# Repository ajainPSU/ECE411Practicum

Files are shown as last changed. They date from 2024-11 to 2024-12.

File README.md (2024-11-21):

# ECE411Practicum

## Team 12 Members:
- Felix Moss
- Davyd Gamza
- Alex Jain
- Anthony Le

### Project: Fingerprint + RFID Lockbox

This repository contains code and resources for the **Fingerprint + RFID Lockbox** project developed as part of the ECE 411 practicum. The project utilizes an **ESP32 Wroom** microcontroller to integrate fingerprint and RFID authentication for a secure lockbox system. The system is capable of reading RFID tags and verifying fingerprints to grant or deny access, with an optional relay mechanism to unlock the box.

---

### Key Features:

- **Fingerprint Authentication:** Using an **Adafruit Fingerprint Sensor** to match user fingerprints.
- **RFID Authentication:** Using the **MFRC522 RFID module** to scan RFID tags and validate the user.
- **TFT Display:** Displays system status and instructions on a **TFT ILI9163C display**.
- **Relay Control:** Unlocks the lockbox for a set duration upon successful authentication.
- **ESP32 Wroom:** The system is built on the **ESP32 Wroom** module, allowing for robust processing and connectivity.

---

### Repository Overview:

- **Bill_of_Materials:** List of components used in the project.
- **Display_Module:** Code for testing the TFT display with the ESP32 Wroom.
- **ESP32_Feather_Wifi_Database (No Longer Needed):** Previously used for WiFi connectivity and database management.
- **ESP32_Practicum:** Updated version of the main project file.
- **Fingerprint Sensor Module:** Code for testing and using the fingerprint sensor.
- **Fully Integrated Module:** Complete system code integrating RFID, fingerprint sensor, and relay.
- **Functional_Decomp:** Decomposition of the system into functional parts for easier development and testing.
- **LockTest:** Testing the lock mechanism functionality.
- **RFID Module:** Code for working with the MFRC522 RFID module.
- **Team_Meeting_Notes:** Notes from team meetings and discussions.
- **Temporary Files:** Placeholder for temporary or discarded files.
- **WroomTest:** Code for testing ESP32 Wroom functionality with serial print statements.

---

### Notes:
- The **ESP32_Feather_Wifi_Database** folder is no longer necessary and has been removed from the active project files.
- Make sure to check the **Fingerprint Sensor Module** and **Fully Integrated Module** for the latest updates on the system functionality.

---

### License:
This project is licensed under the [GPL-3.0 license](LICENSE).

---

### Setup Instructions:

1. **Hardware:**
   - **ESP32 Wroom** module
   - **Adafruit Fingerprint Sensor** (UART-based)
   - **MFRC522 RFID module**
   - **TFT ILI9163C display**
   - **Relay for lock mechanism**

2. **Software:**
   - Install the necessary libraries:
     - **Adafruit Fingerprint Sensor Library**
     - **Adafruit GFX Library**
     - **MFRC522 RFID Library**
     - **TFT ILI9163C Library**

3. **Connections:**
   - Refer to the individual files for pin connections and hardware setup.

---

### Getting Started:
1. Clone the repository to your local machine:
   ```bash
   git clone https://github.com/ajainPSU/ECE411Practicum.git

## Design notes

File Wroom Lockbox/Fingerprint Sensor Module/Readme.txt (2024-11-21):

Note* The enrollment is bugged for esp32_Wroom_fingertest
- Use Enroll_Only to enroll fingerprint on scanner

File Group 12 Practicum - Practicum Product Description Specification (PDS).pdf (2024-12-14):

# Fingerprint Sensor Lock

### Team 12

November 1, 2024

Anthony Le
Alex Jain
Davyd Gamza
Felix Moss

What does it do?

- The user first registers their fingerprint on the device. To access the box, they place their finger on the fingerprint sensor, which sends the input to the processor (Arduino/ESP32). If authorized, the system unlocks the door and displays the message “Authorized”. If unauthorized, a message will appear saying, "You are not authorized."
- The product can be used in many different contexts. Homeowners can secure items without keys, preventing unauthorized access. Businesses can use it for office doors, server rooms, or restricted areas, ensuring only authorized staff can enter. Factories and warehouses can secure equipment rooms or sensitive areas, reducing theft and unauthorized entry. Universities, hospitals, and labs can limit access to sensitive information or materials.

Market Analysis
- People who want to not carry around keys all the time can use this to unlock or enable doors, garages, hatches, etc.
- Competition includes other similar devices such as “Ring” which are electronic types of keys to unlock items. We differ from Ring as we have physical feedback for unauthorized entry attempts.
- Potential selling point is $25. Price is cheap enough to be widely available to everyday users and materials would be around cost once in mass production. The custom pcb, materials, and labor are the driving factors of why it’s priced the way it is.
- Optionally if the customer prefers not to change batteries they can purchase a wall adapter kit for an additional cost, but it will be a battery design from the box.
- Our primary consumers are home and business owners who wish to physically protect their buildings.

Requirements
- Must
- Be plugged into the wall for power.
- Take in fingerprints as input.
- Accurately read fingerprints and verify if the user is authorized.
- Display a message upon reading fingerprint
- Open lock for the user upon activation.
- Store fingerprint information.
- Relock itself after5 Seconds..
- Have an RFID scanner for 2-factor authentication
- May
- Have an optional battery for power to function without the wall plug
- Generate a log whenever the box is accessed or denies entry as a .txt file
- Have a sleek and visually appealing design.
- Re-lock the box and return to waiting for fingerprint input after being closed
- Have cutouts in the housing for the screen and rfid
- Have mounting points or brackets for stability purposes
- Should
- Include user instructions emphasizing proper use and handling to avoid tampering.
- Have user interface options for lock box settings on the display
- Have customizable status updates and alerts for the box owner
- Have a manual lock in case of technical failure
- Stand up to repeated attempts of unauthorized forced entry.

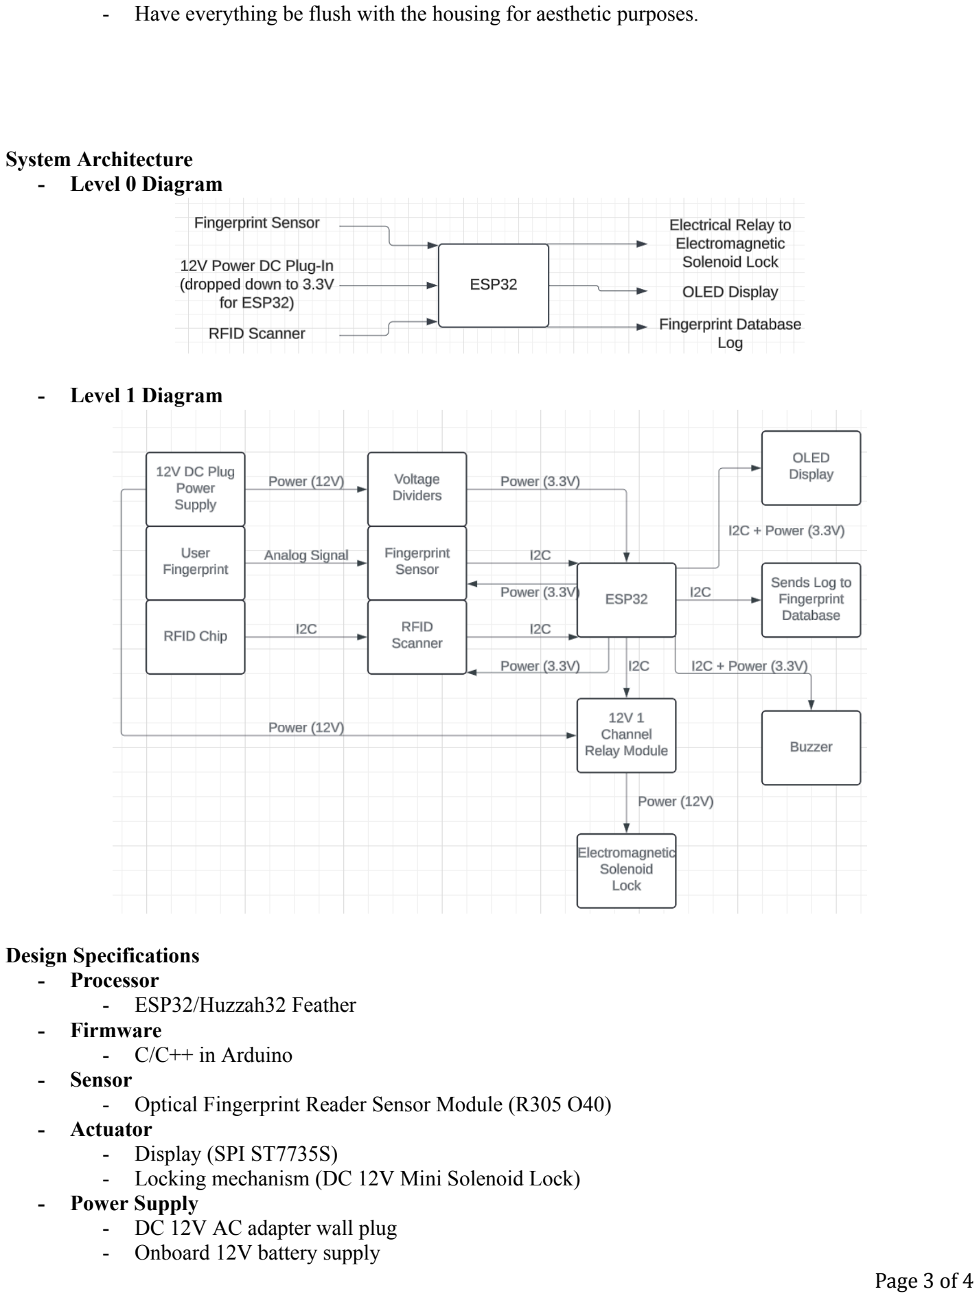
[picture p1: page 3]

- Have everything be flush with the housing for aesthetic purposes.

System Architecture
- Level 0 Diagram
- Level 1 Diagram

Design Specifications
- Processor
- ESP32/Huzzah32 Feather
- Firmware
- C/C++ in Arduino
- Sensor
- Optical Fingerprint Reader Sensor Module (R305 O40)
- Actuator
- Display (SPI ST7735S)
- Locking mechanism (DC 12V Mini Solenoid Lock)
- Power Supply
- DC 12V AC adapter wall plug
- Onboard 12V battery supply

- Secondary battery supply (Higher Voltage)

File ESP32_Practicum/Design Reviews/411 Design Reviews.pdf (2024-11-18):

# Design Review 1

## Conducted by Team 8 (Eric Sanman and Chuong Vo)

# Schematic

- Pull-up resistors for I2C connections
- Move power input to left side of schematic
- Add 0.1uF from 12v input to gnd
- Add box around regulator and other circuit areas for explanation
- Add resistors to high current pin connections

# PCB

- Keep traces away from edges of board, DRC compliant
- Use ground planes better
- 2.54mm between pins
- Use 0805 size resistors, label them on pcb
- Make pcb larger
- Make power traces larger

# Overall

- Add broken component warning

# Design Review 2

## Conducted by Andrew Greenberg (In-Class)

# Schematic

- Use 5V symbol for VCC (instead of lines)
- Add connector symbol to 12V input
- Label connections instead of lines “UR OUT” “UR TX”
- Power to esp ->critical to function-> add capacitors to ground
- Add bypass capacitors to multiple locations as needed
- I^2C missing 4.7k Ohm resistors-> add in physical pull up resistors, don't use software
- 3.3V add symbol and label for where power comes from, don’t use lines
- SDA TO SDK add test points
- Add test points as needed
- Add snubber diode-> reverse bias parallel with the coil
- Add led’s for heartbeat monitoring and for testing
- Use ground symbol instead of wires
- Add test points
- C1 & C2 check floating pins, no pins should be floating-> if floating make it go to a test point->

# PCB

- Add test points
- Use test point diameter .1” or 1mm holes
- Add stitching-> ground to vias
- Use thick wires 10, 20, 30 mm

# Overall

- Version and date are good
- Add to the schematic first then to the PCB
- Relay-> will relay click at 3.3V? (GPIO 32), if not use smaller relay that will click sooner or use the 5 volt rail and try click it

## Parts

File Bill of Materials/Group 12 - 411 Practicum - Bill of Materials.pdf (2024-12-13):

Bill Of Materials for: Group 12
Last modified: 12/12/2024
PCB version: 2.3
BOM revision: 2.3.3 | P/NP = Place/Not Place
Cnt | Part References | P/NP | Mfg | Mfg PN | Description | Dist | Dist Part Number | Cost Ea. | Cost Total
1 | C0 | P | ESPRESSIF | N/A | ESP32 Microcontroller | Amazon | B08D5ZD528 | 5.33 | 5.33
1 | C1 | NP | Handson Tech | N/A | RF RC522 Reader IC Card Sensor Module | Amazon | B07KGBJ9VG | 3.99 | 3.99
1 | C2 | NP | RAJGURU | N/A | Fingerprint Scanner | Amazon | B089LXDG94 | 19.33 | 19.33
1 | C3 | NP | ILITEK | N/A | OLED Display | Amazon | 3-01-1435 | 8.49 | 8.49
1 | C4 | NP | STMicroelectronics | N/A | Voltage Regulator | Mouser | 511-LM317T | 0.63 | 0.63
1 | C5 | NP | HiLetgo | N/A | 5V One Channel Relay Module | Amazon | B00LW15A4W | 3.7 | 3.70
1 | C6 | NP | ATOPLEE | 15060012S02 | Solenoid Lock | Amazon | 759218167424 | 3.99 | 3.99
1 | C7C | NP | California JOS | N/A | 12V DC Power Jack | Amazon | B09ZBN38FS | 1.39 | 6.99
1 | N/A | NP | LitStar | N/A | 12V 2A AC Adapter Charger | Amazon | B0852HX9HV | 11.99 | 11.99
2 | C15, C13 | P | KYOCERA AVX | 08055C104J4T2A | 0.1uF Capacitor | Digikey | 478-KAM21BR71H104JTTR-ND | 0.107 | 0.21
1 | C14 | P | Diodes Inc. | 1N418W-7-F | Rectifier Diode | Digikey | 1N4148W-FDITR-ND | 0.091 | 0.09
2 | C11, C12 | P | onsemi | 1N4007G | Flyback Diode | Digikey | 1N4007GOS-ND | 0.131 | 0.26
1 | C8 | P | Murata Electronics | GRM21BR60G107ME11L | 100uF Capacitor | Digikey | 490-13980-2-ND | 0.458 | 0.46
2 | R4, R5 | P | Panasonic Elec. Comp. | ERJ-6ENF4701V | 4.7k Resistor | Digikey | P4.70KCTR-ND | 0.052 | 0.10
1 | R3 | P | YAGEO | RC0805FR-071KL | 1k Resistor | Digikey | 311-1.00KCRTR-ND | 0.016 | 0.16
1 | R1 | P | Panasonic Elec. Comp. | ERA6AEB241V | 240 Resistor | Digikey | 10-ERA-6AEB241VTR-ND | 0.101 | 1.01
1 | R2 | P | YAGEO | RT0805BRD07723RL | 723 REsistor | Digikey | 13-RT0805BRD07723RLCT-ND | 0.126 | 1.26
1 | C9 | P | KEMET | C0805C106K8PACTU | 10uF Cap | Digikey | 399-C0805C106K8PAC7800CT-ND | 0.073 | 0.07
2 | N/A | NP | PSU Electronic Prototyping Lab | N/A | 3D Printed Box | PSU | N/A | 4.65 | 9.30
1 | N/A | P | OSHPARK | N/A | PCB | OSHPARK | N/A | 9.03 | 9.03
| | | | | | | | TOTAL: | 86.40
VERSION INFO
Rev | Date | Notes
1 | 2024-11-14 Initial BOM
1.2 | 2024-11-18 Updates from Design Reviews
2.3 | 2024-11-20 Verison 2.3 Updates
2.3.1 | 2024-12-4 Formatting and Information Updates
2.3.2 | 2024-12-9 Information Updates
2.3.3 | 2024-12-24 Information Updates

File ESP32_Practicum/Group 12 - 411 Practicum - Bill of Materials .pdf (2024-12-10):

Bill Of Materials for: Group 12
Last modified: 12/9/2024
PCB version: 2.3
BOM revision: 2.3.2 | P/NP = Place/Not Place
Cnt | Part References | P/NP | Mfg | Mfg PN | Description | Dist | Dist Part Number | Cost Ea. | Cost Total
1 | C0 | P | ESPRESSIF | N/A | ESP32 Microcontroller | Amazon | B08D5ZD528 | 5.33 | 15.99
1 | C1 | NP | Handson Tech | N/A | RF RC522 Reader IC Card Sensor Module | Amazon | B07KGBJ9VG | 3.99 | 15.99
1 | C2 | NP | RAJGURU | N/A | Fingerprint Scanner | Amazon | B089LXDG94 | 19.33 | 19.33
1 | C3 | NP | ILITEK | N/A | OLED Display | Amazon | 3-01-1435 | 8.49 | 8.49
1 | C4 | NP | STMicroelectronics | N/A | Voltage Regulator | Mouser | 511-LM317T | 0.63 | 0.63
1 | C5 | NP | HiLetgo | N/A | 2pcs 5V One Channel Relay Module | Amazon | B00LW15A4W | 3.7 | 7.39
1 | C6 | NP | ATOPLEE | 15060012S02 | Solenoid Lock | Amazon | 759218167424 | 3.99 | 15.99
1 | C7C | NP | California JOS | N/A | 12V DC Power Jack | Amazon | B09ZBN38FS | 1.39 | 6.99
1 | N/A | NP | LitStar | N/A | 12V 2A AC Adapter Charger | Amazon | B0852HX9HV | 11.99 | 11.99
2 | C15, C13 | P | KYOCERA AVX | 08055C104J4T2A | 0.1uF Capacitor | Digikey | 478-KAM21BR71H104JTTR-ND | 0.107 | 1.07
1 | C14 | P | Diodes Inc. | 1N418W-7-F | Rectifier Diode | Digikey | 1N4148W-FDITR-ND | 0.091 | 0.91
2 | C11, C12 | P | onsemi | 1N4007G | Flyback Diode | Digikey | 1N4007GOS-ND | 0.131 | 1.31
1 | C8 | P | Murata Electronics | GRM21BR60G107ME11L | 100uF Capacitor | Digikey | 490-13980-2-ND | 0.458 | 4.58
2 | R4, R5 | P | Panasonic Elec. Comp. | ERJ-6ENF4701V | 4.7k Resistor | Digikey | P4.70KCTR-ND | 0.052 | 0.52
1 | R3 | P | YAGEO | RC0805FR-071KL | 1k Resistor | Digikey | 311-1.00KCRTR-ND | 0.016 | 0.16
1 | R1 | P | Panasonic Elec. Comp. | ERA6AEB241V | 240 Resistor | Digikey | 10-ERA-6AEB241VTR-ND | 0.101 | 1.01
1 | R2 | P | YAGEO | RT0805BRD07723RL | 723 REsistor | Digikey | 13-RT0805BRD07723RLCT-ND | 0.126 | 1.26
1 | C9 | P | KEMET | C0805C106K8PACTU | 10uF Cap | Digikey | 399-C0805C106K8PAC7800CT-ND | 0.073 | 0.73
1 | N/A | NP | PSU Electronic Prototyping Lab | N/A | 3D Printed Box | PSU | N/A | 4.65 | 4.65
| | | | | | | | TOTAL: | 118.99
VERSION INFO
Rev | Date | Notes
1 | 2024-11-14 Initial BOM
1.2 | 2024-11-18 Updates from Design Reviews
2.3 | 2024-11-20 Verison 2.3 Updates
2.3.1 | 2024-12-4 Formatting and Information Updates
2.3.2 | 2024-12-9 Information Updates

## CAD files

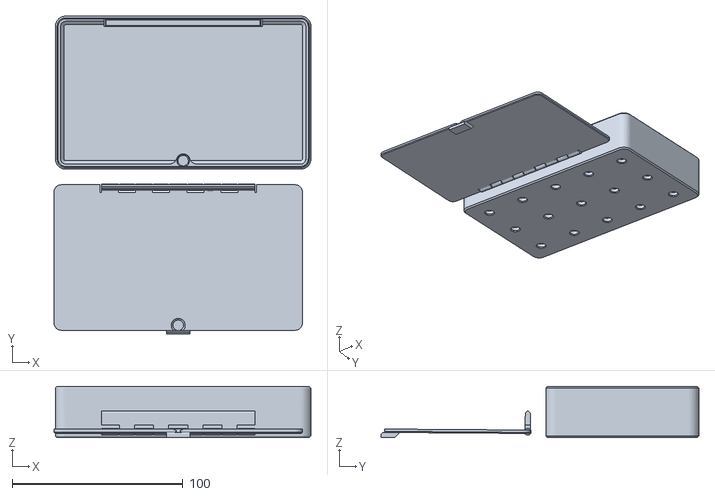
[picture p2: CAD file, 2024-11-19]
Alternatives/Other.stl
150.4 x 186.0 x 30.0

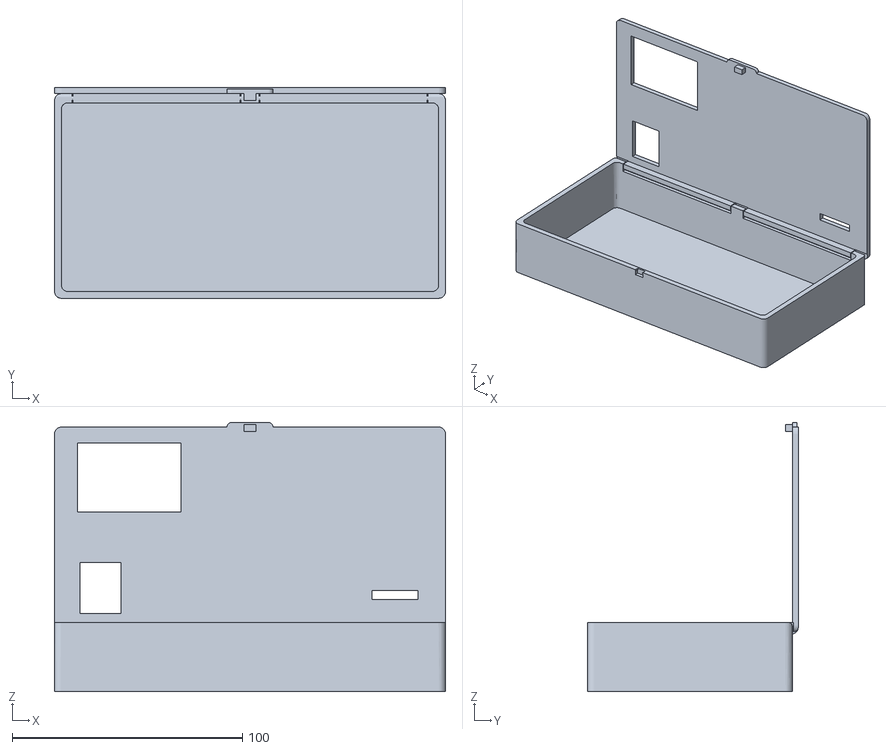
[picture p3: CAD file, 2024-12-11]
Box v3.0/v3.1.stl
170.0 x 91.6 x 117.0

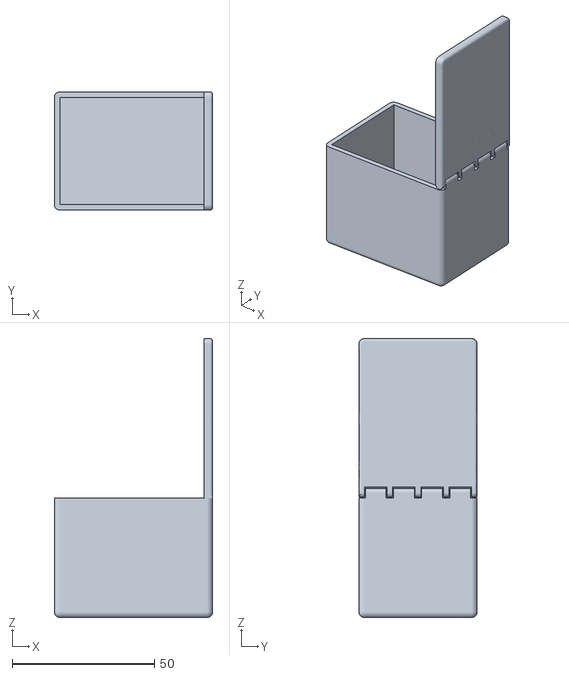
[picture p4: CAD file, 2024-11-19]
Alternatives/Print In Place.stl
55.7 x 41.6 x 98.0

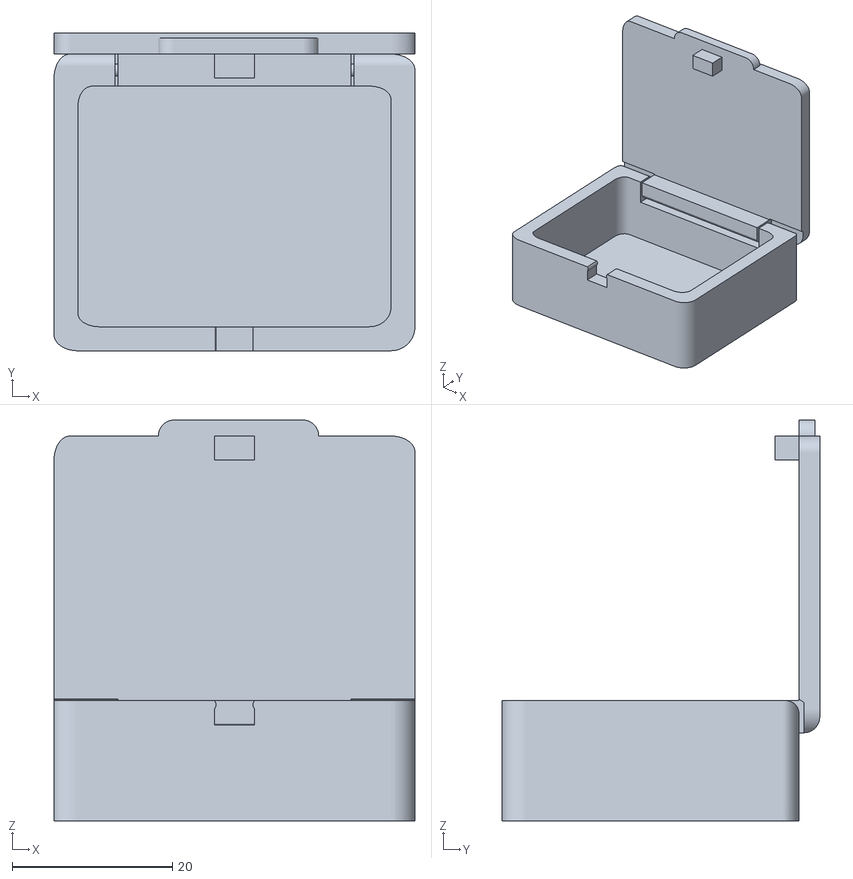
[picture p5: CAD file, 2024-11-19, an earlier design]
Box v.1/v1.1.stl
45.0 x 39.6 x 50.0

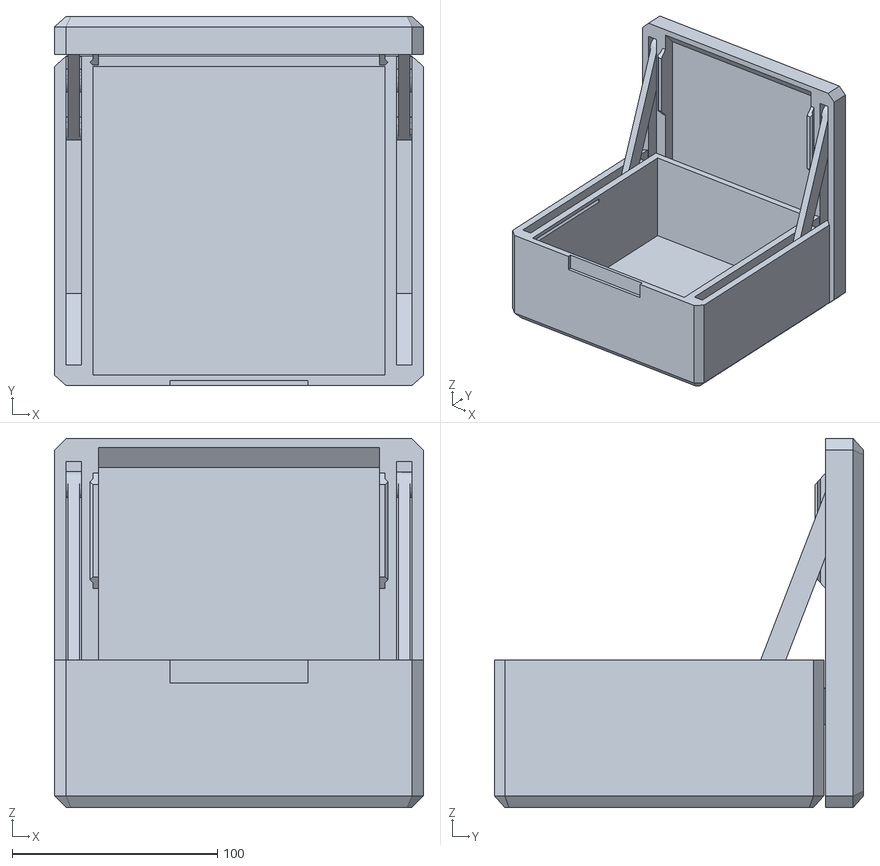
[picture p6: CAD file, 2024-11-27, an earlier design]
Box v2.0/v2.3.stl
180.0 x 180.0 x 180.0

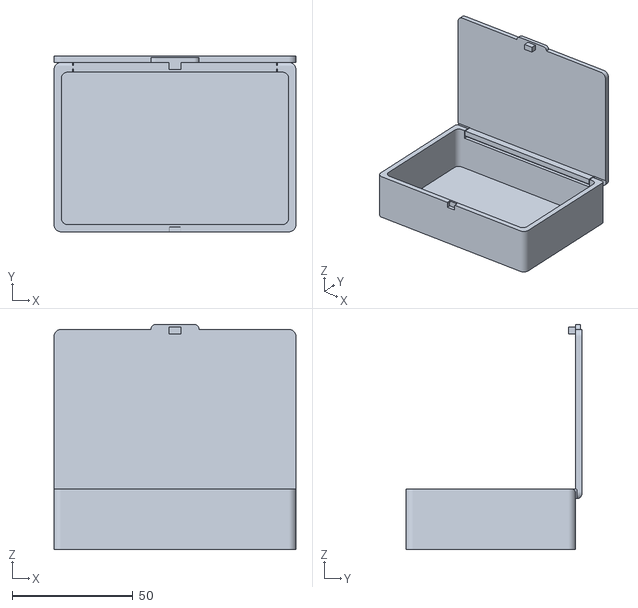
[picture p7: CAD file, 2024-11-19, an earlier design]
Box v.1/v1.2.stl
100.0 x 72.6 x 93.0

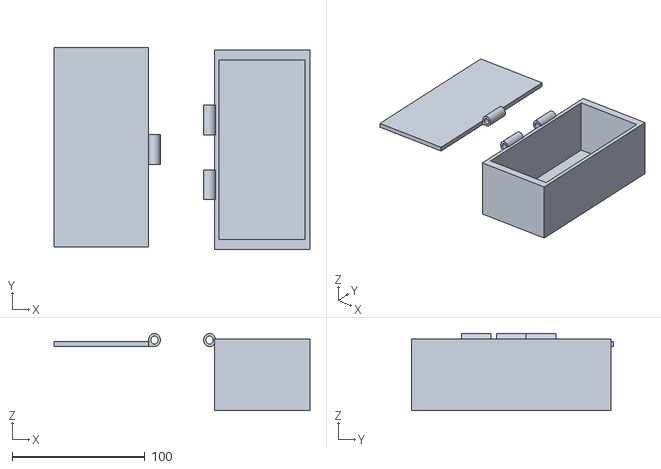
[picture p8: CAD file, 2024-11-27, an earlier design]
Box v2.0/v2.2.stl
192.5 x 152.0 x 58.0

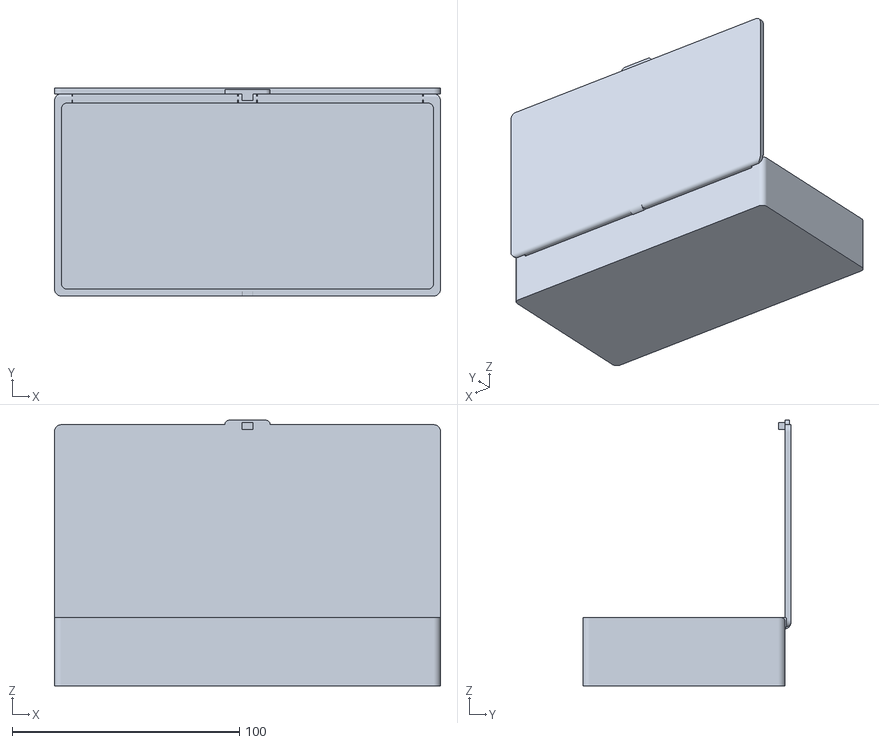
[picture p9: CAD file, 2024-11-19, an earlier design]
Box v.1/v1.3.stl
170.0 x 91.6 x 117.0

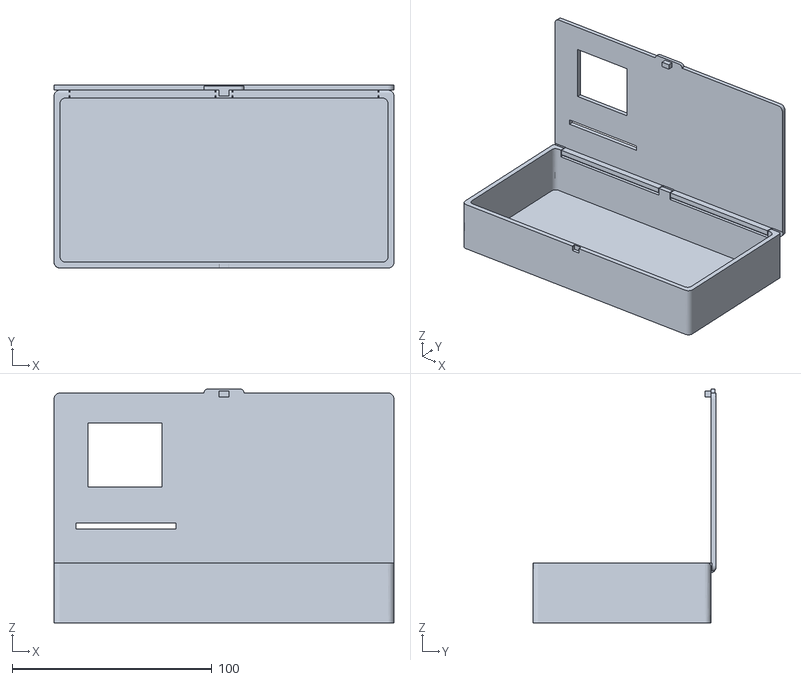
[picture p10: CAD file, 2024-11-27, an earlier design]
Box v2.0/v2.1.stl
170.0 x 91.6 x 117.0

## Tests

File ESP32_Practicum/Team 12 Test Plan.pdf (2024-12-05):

# Team 12 Fingerprint Sensor Lock Box Testing

## List

Unit Tests

### 1. Power Supply Testing

- Verify LM317T regulator provides a stable 3.3V output for ESP32.
- Verify relay module receives 3.3V for actuation.
- Confirm 5V output from the power supply matches specifications.

### 2. ESP32 Microcontroller

- Test ESP32 boot sequence displays proper messages on serial monitor.
- Verify all pins supply correct voltages as per design (e.g., 3.3V, 5V).
- Run the "Blink" program to confirm code upload functionality.

### 3. R307 Fingerprint Sensor

- Test successful enrollment of a fingerprint.
- Verify matching functionality for enrolled fingerprints.
- Test error handling for non-enrolled fingerprints and faulty connections.

### 4. RC522 RFID Module

- Verify pin connections with a multimeter (e.g., continuity testing).
- Test module functionality: scan valid and invalid RFID tags.

### 5. TFT LCD Display

- Verify successful power-on (blank screen).
- Test display functionality for dynamic text changes and color cycling.

### 6. Relay Module and Solenoid Lock

- Verify relay receives appropriate signals from ESP32.
- Confirm solenoid lock actuates correctly when powered.
2024-12-4 | Page 1 of 18

Verification Tests

1. The system boots and displays the correct startup sequence on the LCD.
2. The fingerprint sensor successfully enrolls fingerprints and stores them in the database.
3. The system matches a scanned fingerprint against the database and grants/denies access appropriately.
4. The RFID module correctly identifies valid and invalid tags.
5. Solenoid lock unlocks when the correct fingerprint and RFID tag are scanned.
6. Solenoid lock relocks after a set timeout duration.
7. The LCD updates dynamically during operations (e.g., shows “Access Granted” or “Denied”).
8. Error messages display for failed sensor connections or invalid inputs.
9. Entire system functions under varying input voltages (e.g., 8V, 12V).
10. Database operations work: add, retrieve, delete, and clear fingerprints.
11. Relay and solenoid lock function without signal delays or mismatches.
12. Overall system integration handles sequential operations without malfunction (e.g., RFID → Fingerprint → Unlock).
2024-12-4 | Page 2 of 18

Validation Tests

### 1. Requirement: Access Control

- Test that only a valid RFID and fingerprint combination grants access.

### 2. Requirement: Power Reliability

- Validate the system operates consistently at 12V power supply input.

### 3. Requirement: Error Handling

- Test that an error is displayed when a non-enrolled fingerprint is scanned.
- Simulate a disconnected fingerprint sensor and confirm error detection.

### 4. Requirement: User Feedback

- Validate that all user actions (e.g., scanning RFID, placing a fingerprint) are acknowledged with correct LCD output.

### 5. Requirement: Lock Functionality

- Confirm solenoid lock unlocks for 5 seconds and relocks automatically.

### 6. Requirement: Security

- Test that unregistered RFID tags and fingerprints cannot gain access.

### 7. Requirement: Database Management

- Validate addition, retrieval, and deletion of fingerprint records work as specified.

### 8. Requirement: Display Functionality

- Ensure the TFT LCD correctly displays all critical statuses and instructions.
2024-12-4 | Page 3 of 18

# Matrix Test

Test Author: Felix Moss, Anthony Le

Test Case Name: | Varying Input Voltage Test #1 | Test ID #: | 012
Description: | We will be inputting several different voltages to our circuit and determining if it functions properly. | Type: | ✅white box □ black box □ _____________

Tester Information

| Name of Tester: | Felix Moss | Date: | 12/3/24
| HW/SW Version: | V2.3 | Time: | 4:25 PM
| Setup: | Attach Lab 12V DC Power Supply to PCB for testing.
T E S T | INPUTS | EXPECTED OUTPUTS | P A S S | F A I L | N / A | Comments
1 | 3V3 Input Voltage | Circuit should perform as expected | | ❌ | | No circuit response
2 | 5V Input Voltage | Circuit should perform as expected | | ❌ | | ESP32 barely on, relay on, everything else off
3 | 8V Input Voltage | Circuit should perform as expected | | ❌ | | All circuit elements work except for the solenoid lock.
2024-12-4 | Page 4 of 18

4 | 10V Input Voltage | Circuit should perform as expected | | ❌ | All circuit elements work except for the solenoid lock.
5 | 12V Input Voltage | Circuit should perform as expected | ✅ | | Circuit performs as normal
| Overall test result: | | ✅ | | Circuit performed as expected
2024-12-4 | Page 5 of 18

# Test Cases

Test Author: Anthony Le

Test Case Name: | ESP32 WROOM Blink Test and pin testing #1 | Test ID #: | 001
Description: | Testing the Wroom LED to make sure it can actually upload code and that all the pins that are used are properly working | Type: | ✅ white box □ black box □ ________

Tester Information
| Name of Tester: | Anthony and Felix | Date: | 12/1/2024
| HW/SW Version: | V2.3 | Time: | 5:31 PM
| Setup: | Soldered Wroom to PCB and should blink and have all power pins supplying correct voltages
S T E P | Action | Expected Result | P A S S | F A I L | N / A | Comments
1 | Power on the Wroom | A Red LED should light up on the board meaning there is power | ✅
2 | Blinking LED | A program should run that will blink an led and display message via serial port | ✅
3 | Check power test points | Make sure all the power pins are working properly | | ❌ | | 3.3V was showing 0.7 V but we realized we soldered the Wroom backwards
| Overall test result: | | | ❌ | | Need to fix the Wroom orientation and fix it again
2024-12-4 | Page 6 of 18

Test Author: Anthony Le

Test Case Name: | ESP32 WROOM Blink Test and pin testing #2 | Test ID #: | 002
Description: | Testing the Wroom LED to make sure it can actually upload code and that all the pins that are used are properly working | Type: | ✅ white box □ black box □ ________

Tester Information
| Name of Tester: | Anthony and Felix | Date: | 12/1/2024
| HW/SW Version: | V2.3 | Time: | 5:31 PM
| Setup: | Soldered Wroom to PCB and should blink and have all power pins supplying correct voltages
S T E P | Action | Expected Result | P A S S | F A I L | N / A | Comments
1 | Power on the Wroom | | ✅
2 | Blinking LED | | ✅
3 | Check power test points | | ✅
| Overall test result: | | ✅ | | | After desoldering and resoldering the Wroom, it performed as expected
2024-12-4 | Page 7 of 18

Test Author: Anthony Le
Test Case Name: | Software Fingerprint Sensor R307 Functionalities Test #1 | Test ID #: | 003
Description: | This test case evaluates the performance and functionalities of the R307 Fingerprint Sensor, including fingerprint enrollment, verification, database management, and error handling. The goal is to ensure that the sensor operates reliably and meets specified requirements under various conditions. | Type: | ✅ white box □ black box □ ________

Tester Information
| Name of Tester: | Anthony Le | Date: | 12/01/2024
| HW/SW Version: | V2.3 | Time: | 7:30 PM
| Setup: | Hardware and software setup required for testing R307 Fingerprint Sensor and the connected AS609 chip.
S T E P | Action | Expected Result | P A S S | F A I L | N / A | Comments
1 | Enroll a fingerprint onto the AS609 chip | Place a finger on the sensor, and the system should successfully scan and store the fingerprint. A message confirming the enrollment should be displayed, and the fingerprint data should be added to the database. | ✅ | | | ESP initially did not recognize fingerprints. It was identified as a pin connection issue and was quickly rectified.
2 | Verify fingerprint | Place the same finger on the sensor. The system should recognize the fingerprint, match it to the stored data, and display a success message. | ✅
3 | Display selected fingerprint information | Request details about a specific fingerprint using its ID. The system should retrieve and display relevant information, such as fingerprint ID or storage index. | ✅
4 | Display all fingerprints stored on chip | Request a list of all stored fingerprints. The system should output all fingerprint IDs or indexes currently saved in the database. | ✅
5 | Delete a selected fingerprint | Specify a fingerprint ID to delete. The system should remove the fingerprint from the database and confirm the deletion with a message. | ✅
6 | Clear the fingerprint database | Issue a command to clear the database. The system should | ✅
2024-12-4 | Page 8 of 18

| | delete all fingerprints stored on the chip and display a confirmation message.
7 | Attempt to verify a non-enrolled fingerprint | Place an unregistered finger on the sensor. The system should fail to find a match, display an error message, and deny access. | ✅
8 | Simulate a failed sensor connection | Disconnect the sensor or interrupt communication. The system should detect the issue and display an error indicating a failed connection or unavailability. | ✅
| Overall test result: | | ✅ | Fingerprint scanner performed as expected.
2024-12-4 | Page 9 of 18

Test Author: Anthony Le
Test Case Name: | ESP32 Power Testing #3 | Test ID #: | 004
Description: | Testing all power connections from ESP32 to external modules | Type: | ✅ white box □ black box □ ________

Tester Information
| Name of Tester: | Felix Moss, Anthony Le | Date: | 12/1/24
| HW/SW Version: | V2.3 | Time: | 6:55 PM
| Setup: | Multimeter with alligator clips used on different pins and test points
S T E P | Action | Expected Result | P A S S | F A I L | N / A | Comments
1 | 3V3 Test Point | Should display ~3.3V | ✅
2 | 5V Test Point | Should display ~5V | ✅
3 | R307 VIN + GND | Should display ~3.3V | ✅
4 | RC522 RFID 3V3 + GND | Should display ~3.3V | ✅
5 | Relay Module DC+ + GND | Should display ~3.3V | ✅
6 | ST7735 OLED VCC + GND | Should display ~3.3V | ✅
| Overall test result: | | ✅ | | | All power connections matched expectations
2024-12-4 | Page 10 of 18

Test Author: Felix Moss, Anthony Le
Test Case Name: | Software TFT LCD Display #1 | Test ID #: | 005
Description: | Testing software on the TFT LCD Display | Type: | ✅ white box □ black box □ ________

Tester Information
| Name of Tester: | Felix Moss, Anthony Le | Date: | 12/1/24
| HW/SW Version: | 1.0 | Time: | 7:45 PM
| Setup: | Connect all pins of LCD to appropriate pins on PCB
S T E P | Action | Expected Result | P A S S | F A I L | N / A | Comments
1 | Turn on display | Should display blank screen | ✅
2 | Send signal from ESP32 | Should display “Hello World” text and cycle through colors | | ❌
| Overall test result: | | | ❌ | | LCD only turned on, nothing displayed on screen.
2024-12-4 | Page 11 of 18

Test Author: Felix Moss, Anthony Le
Test Case Name: | Software TFT LCD Display Test #2 | Test ID #: | 006
Description: | Testing software on the TFT LCD Display | Type: | ✅ white box □ black box □ ________

Tester Information
| Name of Tester: | Felix Moss, Anthony Le | Date: | 12/1/24
| HW/SW Version: | 1.2 | Time: | 7:45 PM
| Setup: | Connect all pins of LCD to appropriate pins on PCB
S T E P | Action | Expected Result | P A S S | F A I L | N / A | Comments
1 | Turn on display | Should display blank screen | ✅
2 | Send signal from ESP32 | Should display “Hello World” text and cycle through colors | ✅
| Overall test result: | | ✅ | | | Display performed as expected. Problem was determined to be a pin connection issue.
2024-12-4 | Page 12 of 18

Test Author: Felix Moss, Anthony Le
Test Case Name: | RC522 RFID Pin Connections and Software Testing #1 | Test ID #: | 007
Description: | Testing the pin connections and the software for the RC522 RFID scanner by verifying connections and running test code. | Type: | ✅ white box □ black box □ ________

Tester Information
| Name of Tester: | Felix Moss, Anthony | Date: | 12/1/24
| HW/SW Version: | V2.3 | Time: | 8:15 PM
| Setup: | Attach probes to Multimeter. Attach RC522 to appropriate pins.
S T E P | Action | Expected Result | P A S S | F A I L | N / A | Comments
1 | Test all RC522 pin connections | When touching the pin on the PCB to the corresponding pin on the ESP32, a beep should be heard | ✅
2 | Turn on RC522 | Should turn on red LED on scanner | ✅
3 | Upload software | Scans for RFID card and UID. Displays “Access Granted” on serial monitor if ID is correct. Displays “Access Denied” on serial monitor if ID is incorrect | ✅
| Overall test result: | | ✅ | | | RC522 performed as expected
2024-12-4 | Page 13 of 18

Test Author: Felix Moss, Anthony Le
Test Case Name: | Relay Module and Solenoid Lock Test #1 | Test ID #: | 008
Description: | Testing the pin connections and the software for the Relay Module and Solenoid Lock | Type: | ✅ white box □ black box □ ________

Tester Information
| Name of Tester: | Felix Moss, Anthony | Date: | 12/1/24
| HW/SW Version: | V2.3 | Time: | 8:45 PM
| Setup: | Attach probes to Multimeter. Attach Relay Module and Solenoid Lock to appropriate pins.
S T E P | Action | Expected Result | P A S S | F A I L | N / A | Comments
1 | Test all pin connections | When touching the pin on the PCB to the corresponding pin on the ESP32, a beep should be heard. | | ❌ | | Pin NO incorrectly routed. Fixed by connecting NO on the module directly to ground and leaving NO on the PCB unconnected.
2 | Turn on Relay Module | A red LED should light up on the Relay Module when the ESP32 is powered on | ✅
3 | Upload software | Solenoid lock should open and close | ✅
| Overall test result: | | ✅ | | | The relay performed as expected. However, since the NO pin on the PCB is wired incorrectly, the NO pin on the relay had to be directly wired to ground.
2024-12-4 | Page 14 of 18

Test Author: Felix Moss, Anthony Le
Test Case Name: | Full Integrated Test #1 | Test ID #: | 009
Description: | Testing the entire mechanism with all modules attached. | Type: | ✅ white box □ black box □ ________

Tester Information
| Name of Tester: | Felix Moss, Anthony | Date: | 12/1/24
| HW/SW Version: | V2.3 | Time: | 9:30 PM
| Setup: | Attach all modules to PCB. Run test software
S T E P | Action | Expected Result | P A S S | F A I L | N / A | Comments
1 | Run startup software | Display should show text saying, “Booting up System…”, “Fingerprint Sensor And RFID Scanner Initializing…”, “Access Control System”, and Finger Sensor Ready” | ✅
2 | Scan incorrect RFID | Display should show text saying, “Access Denied” and then return to “Scan RFID…” | ✅
3 | Scan correct RFID | Display should show text saying, “RFID Valid” and then show, “Place finger” | ✅
4 | Scan incorrect fingerprint | Display should show text saying, “Finger No Match” and then return to “Scan RFID” | ✅
5 | Scan correct RFID | Display should show text saying, “Access Granted” and then show, “Place finger” | ✅
6 | Scan correct fingerprint | Display should show text saying, “Access Granted, ID [User ID Number]” | ✅
7 | Solenoid Unlocks | Solenoid should unlock and display should say, “ Unlocked”. The lock should close after 5 seconds. | ✅
8 | Solenoid Locks | Solenoid should re-lock. The display should say, “ Locked”, | ✅
2024-12-4 | Page 15 of 18

| then return to “Scan RFID…”
Overall test result: | | ✅ | Mechanism performed as expected
2024-12-4 | Page 16 of 18

Test Author: Felix Moss

Test Case Name: | LM317T Testing #1 | Test ID #: | 010
Description: | Testing the LM317T voltage regulator to see if it can power the ESP32 with a 12V source. | Type: | ✅ white box □ black box □ ________

Tester Information
| Name of Tester: | Felix Moss | Date: | 12/3/2024
| HW/SW Version: | V2.3 | Time: | 12:30 PM
| Setup: | Solder LM317T to board. Set DC power supply to 12V and attach to board. Attach probes to Multimeter.
S T E P | Action | Expected Result | P A S S | F A I L | N / A | Comments
1 | Test LM317T pin connections | When touching the pin on the PCB to the corresponding pin on the ESP32, a beep should be heard. | ✅
2 | Turn on 12V power | A Red LED should light up on the ESP32 meaning there is power | | ❌ | | No light appeared and the power supply showed signs of a short.
| Overall test result: | | | ❌ | | Check all pin connections and rerun test
2024-12-4 | Page 17 of 18

Test Author: Felix Moss

Test Case Name: | LM317T Testing #2 | Test ID #: | 011
Description: | Testing the LM317T voltage regulator to see if it can power the ESP32 with a 12V source. | Type: | ✅ white box □ black box □ ________

Tester Information
| Name of Tester: | Felix Moss | Date: | 12/3/2024
| HW/SW Version: | V2.3 | Time: | 12:30 PM
| Setup: | Solder LM317T to board. Set DC power supply to 12V and attach to board. Attach probes to Multimeter.
S T E P | Action | Expected Result | P A S S | F A I L | N / A | Comments
1 | Test LM317T pin connections | When touching the pin on the PCB to the corresponding pin on the ESP32, a beep should be heard. | ✅
2 | Turn on 12V power | A Red LED should light up on the ESP32 meaning there is power | ✅
| Overall test result: | | ✅ | | | Problem was determined to be a short of some kind and was quickly rectified.
2024-12-4 | Page 18 of 18

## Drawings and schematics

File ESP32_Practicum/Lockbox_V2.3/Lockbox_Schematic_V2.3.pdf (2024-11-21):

D22 14 | D23 15 | D25 23 | D26 24 | D27 25 | D32 21 | D33 22 | D35 20 | D34 19

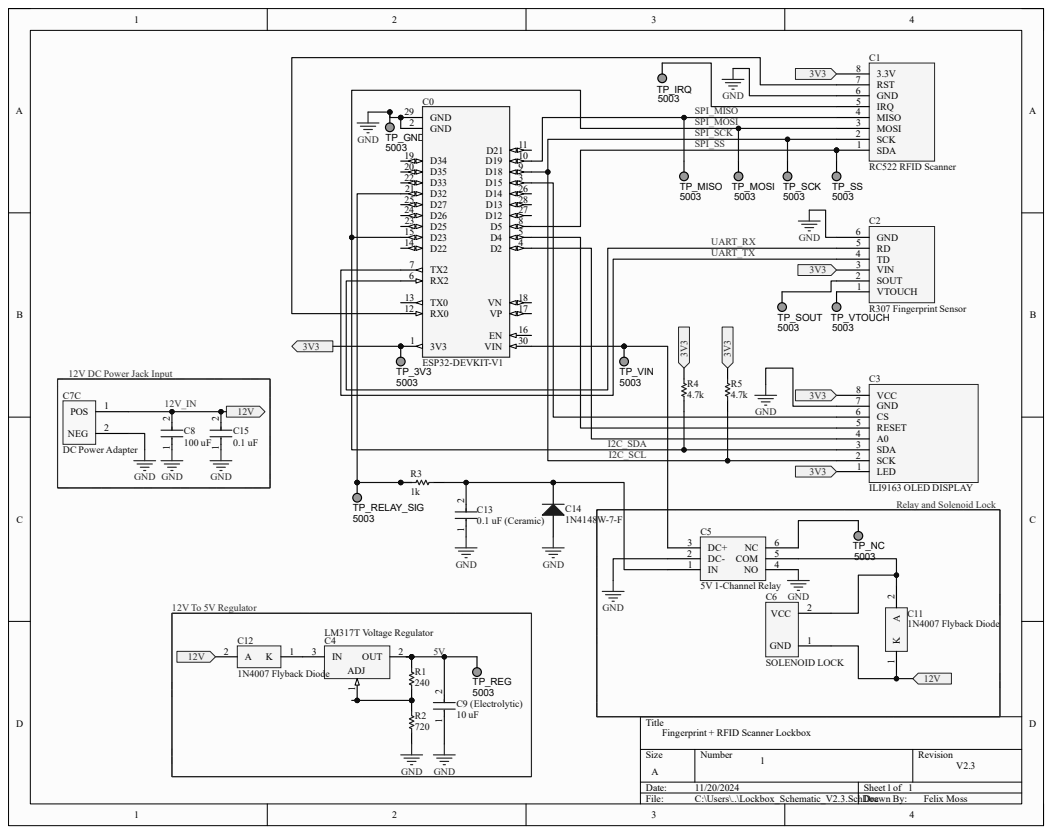
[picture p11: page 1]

12V DC Power Jack Input

ILI9163 OLED DISPLAY
Relay and Solenoid Lock

Title
Fingerprint + RFID Scanner Lockbox

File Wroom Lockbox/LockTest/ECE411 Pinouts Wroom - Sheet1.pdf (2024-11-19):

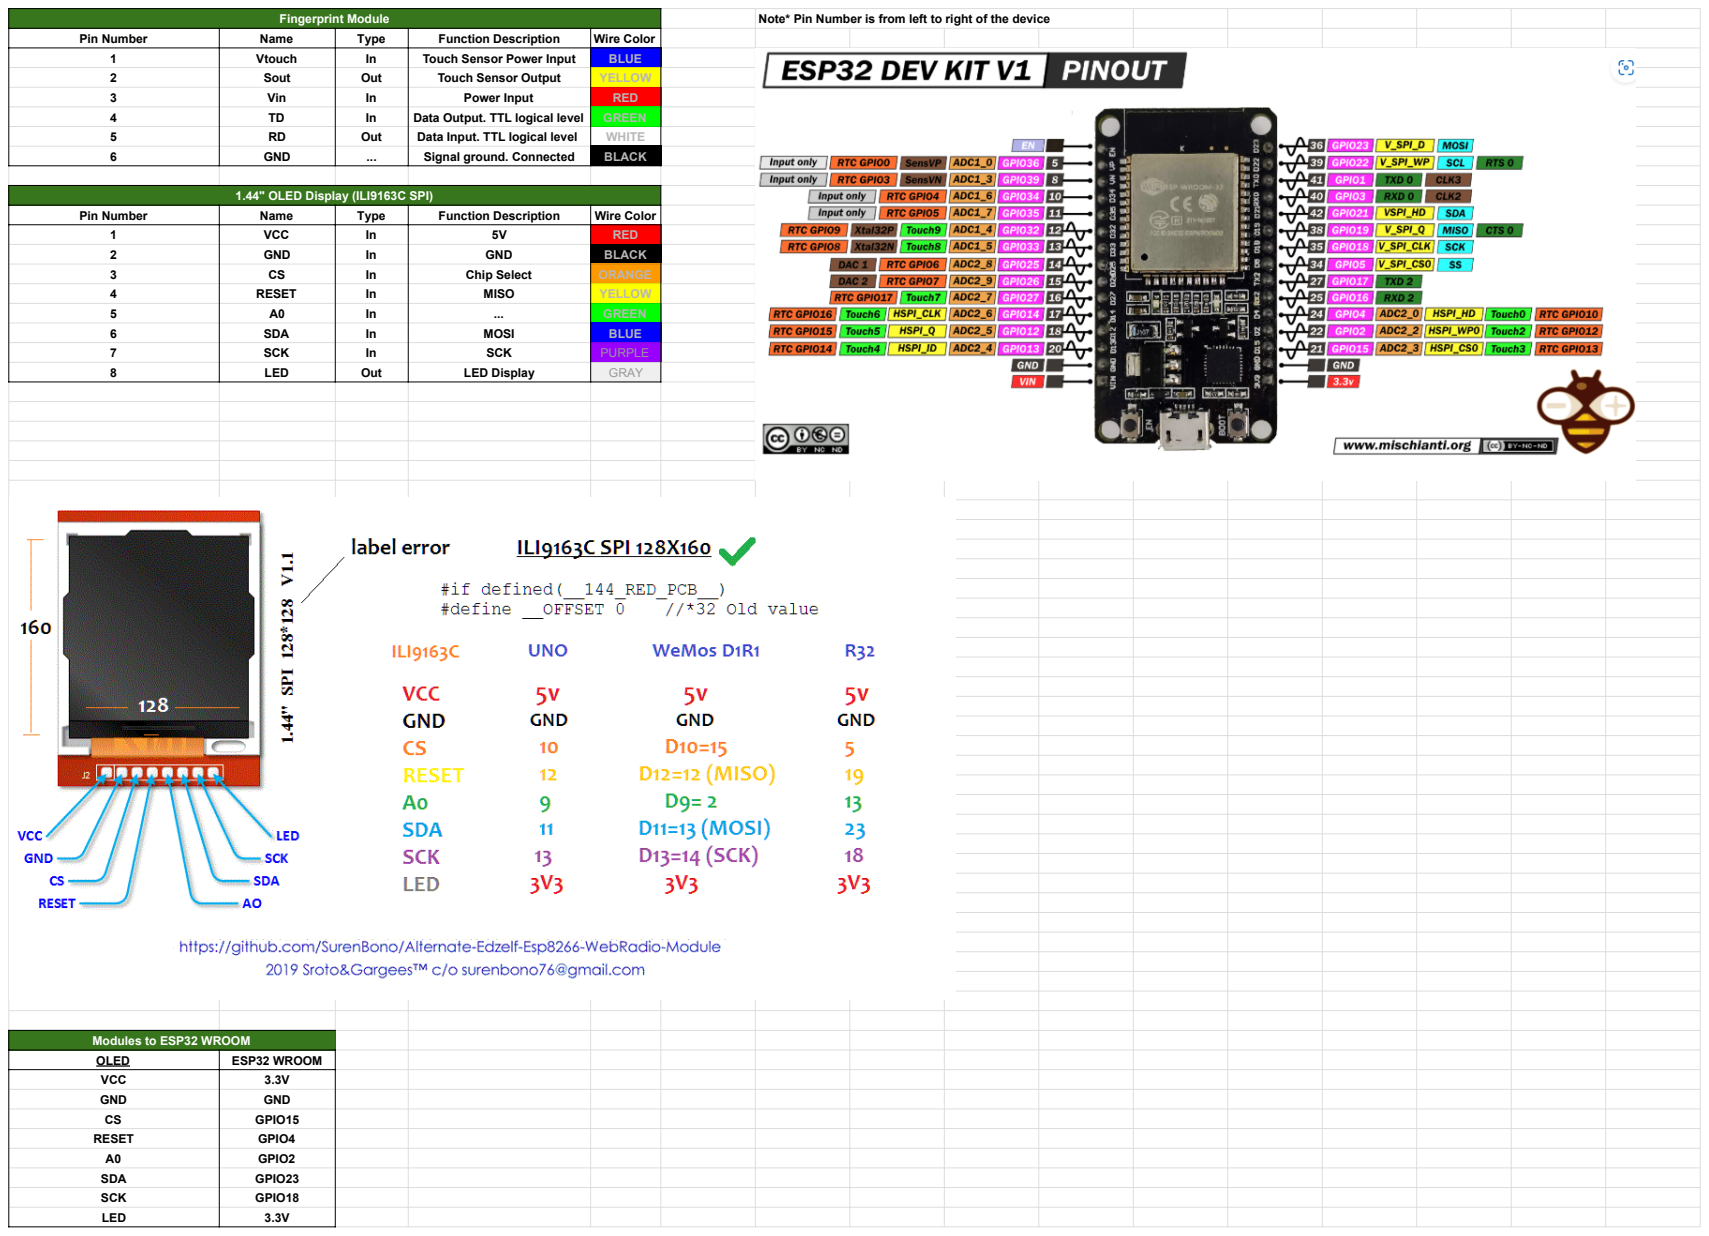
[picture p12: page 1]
Fingerprint Module; Note* Pin Number is from left to right of the device

Pin Number | Name | Type | Function Description | Wire Color
1 2 3 4 5 6 | Vtouch Sout Vin TD RD GND | In Out In In Out ... | Touch Sensor Power Input Touch Sensor Output Power Input Data Output. TTL logical level Data Input. TTL logical level Signal ground. Connected | BLUE YELLOW RED GREEN WHITE BLACK

1.44" OLED Display (ILI9163C SPI)

1 2 3 4 5 6 7 8 | VCC GND CS RESET A0 SDA SCK LED | In In In In In In In Out | 5V GND Chip Select MISO ... MOSI SCK LED Display | RED BLACK ORANGE YELLOW GREEN BLUE PURPLE GRAY

Modules to ESP32 WROOM

OLED | ESP32 WROOM
VCC GND CS RESET A0 SDA SCK LED | 3.3V GND GPIO15 GPIO4 GPIO2 GPIO23 GPIO18 3.3V

Fingerprint Sensor | ESP32 WROOM
BLUE (Vtouch) RED (Vin) YELLOW (Sout) GREEN (TD) WHITE (RD) BLACK SCK LED | ---3.3V ---GPIO16 (RX_PIN) GPIO17 (TX_PIN) GND GPIO18 3.3V

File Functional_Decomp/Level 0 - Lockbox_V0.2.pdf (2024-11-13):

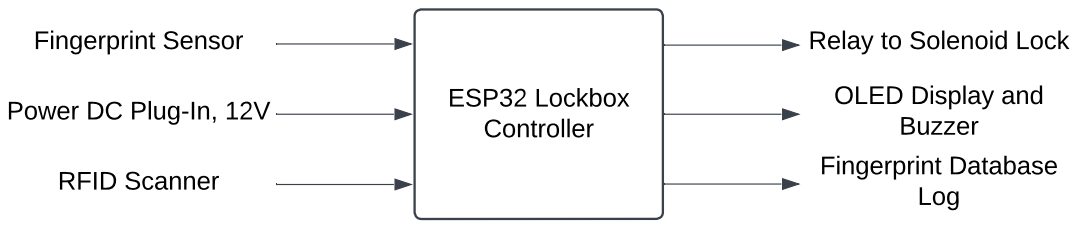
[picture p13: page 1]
olle; Plu; Dis; pla; Fin; rin; FID; ela; ole; oid

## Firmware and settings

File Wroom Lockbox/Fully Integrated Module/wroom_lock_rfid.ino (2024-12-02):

/*  
ESP32 (Wroom) - RFID and Fingerprint Access Control System  
Combines RFID and fingerprint authentication to unlock for a set duration.  
Checks RFID tag first, followed by fingerprint matching.  
If both pass, it unlocks for a defined amount of time.  

Author: Alex Jain <ajain@pdx.edu>, Anthony Le <anthle@pdx.edu>  
Date: Dec 2nd, 2024  
Version: 0.6  

Necessary Libraries:  
1. Adafruit Fingerprint Sensor Library: https://github.com/adafruit/Adafruit-Fingerprint-Sensor-Library  
2. Adafruit GFX Library: https://github.com/adafruit/Adafruit-GFX-Library  
3. TFT ILI9163C Library: https://github.com/sumotoy/TFT_ILI9163C  
4. MFRC522 RFID Library: https://github.com/miguelbalboa/rfid  

Hardware Requirements:  
1. ESP32 Wroom/Feather Dev Module  
2. TFT ILI9163C Display  
3. Adafruit Fingerprint Sensor (UART-based)  
4. MFRC522 RFID Module  
5. Relay for lock mechanism  

Note: Ensure all pin connections match the pin definitions in the code.  
*/

// Library Headers
#include <SPI.h>
#include <Adafruit_GFX.h>
#include <HardwareSerial.h>
#include <Adafruit_Fingerprint.h>
#include <TFT_ILI9163C.h>
#include <MFRC522.h>

// Pin Definitions
#define __CS 15     // Chip Select for TFT as GPIO 15
#define __DC 2      // Data/Command for TFT as GPIO 2
#define A0 4        // Reset for TFT as GPIO 4
#define SCK 18      // Clock for TFT as GPIO 18
#define RX_PIN 16   // RX2 for fingerprint sensor
#define TX_PIN 17   // TX2 for fingerprint sensor

#define SS_PIN 5    // Chip Select for RFID as GPIO 5
#define RST_PIN 3   // Reset for RFID as GPIO 3
#define RELAY_PIN 32 // Relay to control lock mechanism as GPIO 32

// Unlock duration in seconds
#define UNLOCK_TIME 5

// RFID Tag UID (Replace with your own)
byte keyTagUID[4] = {0x39, 0xFB, 0xFF, 0x00};

// Color definitions for TFT
// Define color in 16-bit RGB format
#define BLACK   0x0000
#define BLUE    0x001F
#define RED     0xF800
#define GREEN   0x07E0
#define CYAN    0x07FF
#define MAGENTA 0xF81F
#define YELLOW  0xFFE0
#define WHITE   0xFFFF

// Not sure how to make this look like actual fingerprint
// const uint8_t fingerprintBitmap[] PROGMEM = {
//   // 128x128 Fingerprint Image Bitmap (each byte represents 8 pixels)
//   0x00, 0x00, 0x00, 0x00, 0x00, 0x00, 0x00, 0x00, // Row 1
//   0x00, 0x1C, 0x3E, 0x3E, 0x1C, 0x00, 0x00, 0x00, // Row 2
//   0x00, 0x3E, 0x7F, 0x7F, 0x3E, 0x00, 0x00, 0x00, // Row 3
//   0x00, 0x3E, 0x7F, 0x77, 0x3E, 0x1C, 0x00, 0x00, // Row 4
//   0x00, 0x1C, 0x3E, 0x77, 0x77, 0x3E, 0x00, 0x00, // Row 5
//   0x00, 0x00, 0x1C, 0x3E, 0x77, 0x3E, 0x1C, 0x00, // Row 6
//   0x00, 0x00, 0x00, 0x1C, 0x3E, 0x3E, 0x3E, 0x00, // Row 7
//   0x00, 0x00, 0x00, 0x00, 0x1C, 0x3E, 0x1C, 0x00, // Row 8
//   // Repeat pattern or add unique details for the remaining rows
// };


// Instantiate objects
TFT_ILI9163C tft(__CS, __DC, A0);       // TFT Display
HardwareSerial mySerial(2);            // Serial2 for fingerprint sensor
Adafruit_Fingerprint finger(&mySerial);
MFRC522 rfid(SS_PIN, RST_PIN);         // RFID Reader

void setup() {
  // Initialize serial communication
  Serial.begin(115200);
  mySerial.begin(57600, SERIAL_8N1, RX_PIN, TX_PIN);
  Serial.print("Initializing Display...\n");
  // Initialize TFT display
  tft.begin();
  tft.setRotation(2); // Adjust rotation for your specific setup
  tft.fillScreen(BLACK);
  tft.setTextColor(WHITE);
  tft.setTextSize(1);
  tft.setCursor(0, 0);

  Serial.print("Initializing System...\n");
  // Boot-up message with animation
  for (int i = 1; i <= 3; i++) {
    tft.fillScreen(BLACK); // Clear the screen for each frame
    tft.setCursor(10, 30);
    tft.println("Booting up");

    // Add dots based on the current iteration
    if (i == 1) {
      tft.println("  System.");
    } else if (i == 2) {
      tft.println("  System..");
    } else if (i == 3) {
      tft.println("  System...");
    }
    delay(1000); // Wait for 1 second per frame
  }
  delay(1000); // Additional delay before moving on

  Serial.print("Initializing RFID/Finger Sensor...\n");
  // Initialize RFID reader
  SPI.begin();
  rfid.PCD_Init();

  // Display fingerprint image w/ animation
  for (int i = 1; i <= 3; i++) {
    tft.fillScreen(BLACK); // Clear the screen for each frame
    tft.setCursor(10, 30);
    tft.println("Fingerprint Sensor\n\n  And RFID Scanner");

    // Add dots based on the current iteration
    if (i == 1) {
      tft.println("\n Initializing.");
    } else if (i == 2) {
      tft.println("\n Initializing..");
    } else if (i == 3) {
      tft.println("\n Initializing...");
    }
    delay(800); // Wait for 1 second per frame
  }
  delay(1000); // Additional delay before moving on
  
  // Just for fun if we can get it to work
  // Draw the fingerprint image (use a 128x128 bitmap)
  // tft.drawBitmap(0, 0, fingerprintBitmap, 128, 128, WHITE); // Centered on display
  // delay(3000); // Wait for 3 seconds

  // Display system message
  tft.fillScreen(BLACK);
  tft.setTextSize(2);
  tft.setCursor(10, 20);
  tft.println("Access");
  tft.setCursor(10, 60);
  tft.println("Control");
  tft.setCursor(10, 100);
  tft.println("System");
  delay(3000); // Wait for 3 seconds

  // Display startup message
  tft.println(" \n\n Access\n Control\n System");
  delay(2000);

  Serial.print("Finger Sensor Ready...\n");
  // Initialize fingerprint sensor
  if (finger.verifyPassword()) {
    tft.fillScreen(BLACK);
    tft.println(" \n\n Finger\n Sensor\n Ready");
    delay(2000);
  } else {
    tft.fillScreen(RED);
    tft.println(" \n Finger\n Sensor\n Error");
    while (1); // Halt if fingerprint sensor fails to initialize
  }

  // Configure relay pin
  pinMode(RELAY_PIN, OUTPUT);
  digitalWrite(RELAY_PIN, LOW); // Ensure lock is locked initially
}

void loop() {
  // Step 1: Prompt user to scan RFID tag
  tft.fillScreen(BLACK);
  tft.setCursor(0, 0);
  tft.println(" \n\n Scan\n RFID...");
  Serial.print("RFID Ready...\n");
  if (rfid.PICC_IsNewCardPresent() && rfid.PICC_ReadCardSerial()) {
    if (verifyRFID()) {
      // RFID verified, prompt for fingerprint
      tft.fillScreen(GREEN);
      tft.setCursor(0, 0);
      tft.println(" \n\n RFID \n Valid\n ");
      Serial.print("Access Granted, UID:");
      for (int i = 0; i < rfid.uid.size; i++) {
        Serial.print(rfid.uid.uidByte[i] < 0x10 ? " 0" : " ");
        Serial.print(rfid.uid.uidByte[i], HEX);
      }
      Serial.println();
      Serial.print("Waiting for fingerprint\n");
      delay(2000);
      tft.fillScreen(BLACK);
      tft.setCursor(0, 0);
      tft.println(" \n\n  Place\n  Finger\n ");
      
      // Step 2: Scan fingerprint
      int id = getFingerprintID();
      if (id != -1) {
        // Fingerprint matched, grant access
        tft.fillScreen(GREEN);
        tft.setCursor(0, 0);
        tft.print(" \n\n Access\n Granted\n ID: ");
        tft.println(id);
        delay(2000);
        // Unlock for the defined duration
        unlockDoor();
      } else {
        // Fingerprint mismatch
        tft.fillScreen(RED);
        tft.setCursor(0, 0);
        tft.println(" \n\n Finger\n Does Not\n Match");
        delay(2000);
      }
    } else {
      // RFID mismatch
      tft.fillScreen(RED);
      tft.setCursor(0, 0);
      tft.println(" \n\n RFID\n Denied");
      Serial.print("Access denied, UID:");
      for (int i = 0; i < rfid.uid.size; i++) {
        Serial.print(rfid.uid.uidByte[i] < 0x10 ? " 0" : " ");
        Serial.print(rfid.uid.uidByte[i], HEX);
      }
      Serial.println();
      delay(2000);
    }
    rfid.PICC_HaltA();
    rfid.PCD_StopCrypto1();
  } else {
    // No RFID detected
    delay(1000); // Short delay before re-prompting
  }
}

bool verifyRFID() {
  // Compare scanned RFID tag with the stored UID
  for (byte i = 0; i < 4; i++) {
    if (rfid.uid.uidByte[i] != keyTagUID[i]) return false;
  }
  return true;
}

int getFingerprintID() {
  int result = FINGERPRINT_NOFINGER;
  while (result != FINGERPRINT_OK) {
    result = finger.getImage();
    if (result == FINGERPRINT_OK) break;
    if (result == FINGERPRINT_NOFINGER) continue;
    return -1; // Error or timeout
  }

  result = finger.image2Tz();
  if (result != FINGERPRINT_OK) return -1;

  result = finger.fingerFastSearch();
  if (result != FINGERPRINT_OK) return -1;

  return finger.fingerID; // Return matched ID
}

void unlockDoor() {
  // Unlock animation and door unlocking
  Serial.println(" Unlocking...");
  digitalWrite(RELAY_PIN, HIGH); // Unlock the door

  Serial.println(" Unlocked.");
  tft.fillScreen(GREEN);
  tft.setCursor(0, 0);
  tft.println(" \n\n Unlocked");

  // Wait for UNLOCK_TIME before locking the door
  delay(UNLOCK_TIME * 1000); // UNLOCK_TIME-second delay

  // Lock animation and door locking
  Serial.println("Locking...");
  digitalWrite(RELAY_PIN, LOW); // Relock the door

  tft.fillScreen(BLUE);
  tft.setCursor(0, 0);
  tft.println(" \n\n Locked");
  Serial.println(" Locked.");
  delay(2000); // Additional UI display time
}

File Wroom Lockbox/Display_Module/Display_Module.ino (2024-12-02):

/*
  ESP32 TFT Display - Hello World Example
  
  This simple program demonstrates how to display "Hello World" on an ILI9163C TFT display connected to an ESP32.
  The program cycles through all available colors on the screen and prints the respective color name.
  
  Author: Anthony Le <anthle@pdx.edu>  
  Date: Dec 1st, 2024  
  Version: 1.3  
  
  Necessary Libraries:
  1. Adafruit GFX Library: https://github.com/adafruit/Adafruit-GFX-Library
  2. TFT ILI9163C Library: https://github.com/sumotoy/TFT_ILI9163C
  
  Hardware Requirements:
  1. ESP32 Wroom/Feather Dev Module
  2. TFT ILI9163C Display
*/

#include <SPI.h>                 // SPI library for communication with the TFT
#include <Adafruit_GFX.h>        // Adafruit GFX library for graphics functions
#include <TFT_ILI9163C.h>        // TFT ILI9163C library for the specific display

// Pin Definitions for TFT Display
#define __CS  15  // Chip Select pin
#define __DC  2   // Data/Command pin
#define A0    4   // Reset pin
#define SCK   18  // Clock pin

// Color Definitions (16-bit RGB format)
#define BLACK   0x0000
#define BLUE    0x001F
#define RED     0xF800
#define GREEN   0x07E0
#define CYAN    0x07FF
#define MAGENTA 0xF81F
#define YELLOW  0xFFE0
#define WHITE   0xFFFF

#define TIME 2  // Delay time in seconds

// Create a TFT display object using the defined pin connections
TFT_ILI9163C tft(__CS, __DC, A0);

void setup() {
  // Initialize Serial communication for debugging (115200 baud rate)
  Serial.begin(115200);
  Serial.println("Booting up Display Program...\n");

  // Initialize the TFT display
  tft.begin();
  tft.setRotation(2);          // Adjust the screen orientation
  tft.fillScreen(BLACK);       // Set the initial background color to black
  tft.setTextColor(WHITE);     // Set the text color to white
  tft.setTextSize(2);          // Set the text size to medium

  // Display "Hello World" message
  tft.setCursor(10, 30);       // Set cursor position (x=10, y=30)
  tft.println("Hello\nWorld"); // Print "Hello World" on the TFT screen
  delay(TIME * 1000);

  // Cycle through and display all available colors
  displayColor("Black", BLACK, WHITE);
  displayColor("Blue", BLUE, WHITE);
  displayColor("Red", RED, WHITE);
  displayColor("Green", GREEN, WHITE);
  displayColor("Cyan", CYAN, WHITE);
  displayColor("Magenta", MAGENTA, WHITE);
  displayColor("Yellow", YELLOW, WHITE);
  displayColor("White", WHITE, BLACK);
}

void loop() {
  // No operations in the loop for this example.
  // All actions are performed once during setup.
}

/**
 * @brief Displays a specified color on the TFT screen.
 * 
 * @param colorName Name of the color to display (e.g., "Red").
 * @param bgColor Background color to fill the screen.
 * @param textColor Text color to use for the label.
 */
void displayColor(const char* colorName, uint16_t bgColor, uint16_t textColor) {
  Serial.printf("%s.\n", colorName); // Print color name to Serial Monitor
  tft.fillScreen(bgColor);           // Fill the screen with the specified background color
  tft.setTextColor(textColor);       // Set the text color
  tft.setCursor(10, 30);             // Position the cursor for text display
  tft.println(colorName);            // Print the color name on the screen
  delay(TIME * 1000);                // Pause for the specified duration
}

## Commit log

2024-11-02 Added test code for fingerprint sensor w/ ESP32
    Added code that enrolls the user's fingerprint from the fingerprint sensor to the ESP32
2024-11-07 Uploaded temporary progress of ESP32 Wifi Database
    Added temporary code to fix later as well as progress on creating the google sheets data base and interfacing it with ESP32 Feather. Arduino code will read and write to google sheets but still in progress.
    [esp32_wifi.ino]
2024-11-07 Update and rename LCDPinout to Device Pinout
2024-11-07 Update esp32_wifi.ino with code for ESP32
    Took out unnecessary lines of code and reformatted.
2024-11-07 Uploaded image of breadboard prototype
2024-11-07 Updated esp32_f_fingerprint.ino
2024-11-08 Update esp32_wifi.ino with working code
2024-11-08 Added comments esp32_wifi.ino
2024-11-13 Updated Google Apps Script Web App URL for data submission esp32_wifi.ino
2024-11-13 Updated code for esp32_wifi.ino
2024-11-14 UPDATED BOM
2024-11-17 Lockbox Schematic V1.1
    Updated schematic after in-class design review. Will update PCB layout soon
2024-11-18 Version 1.2 of Schematic
    Updated using design review feedback from Greenberg and Team 8
2024-11-19 Updated README.md ESP32_Feather_Wifi_Database no longer needed
2024-11-19 Rearranged files to ESP32_Practicum and added a Wroom Test to make sure device works on plug in.
2024-11-19 Added print statements to Wroom testing
2024-11-19 Test code for fingerprint module
2024-11-19 Uploaded Wroom version of code
    Bugs*
    - Enroll will constantly loop but it does enroll the fingerprint
    - Enters random data when back to menu
    [esp32_Wroom_fingertest.ino]
2024-11-19 Updated LED text to be more in line for locktest3_Wroom.ino
2024-11-19 Update esp32_Wroom_fingertest.ino fixed bugs listed from before
    [esp32_Wroom_fingertest.ino]
2024-11-19 Temporary Files
    Pending modifications but not quite done
    [Amazing Albar.stl, Hinge_Box-37-45-15.stl, Hinge_Box-70-100-25.stl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]
2024-11-19 Create Millis-type
2024-11-20 Update esp32_Wroom_fingertest.ino fixed bug where fingerprint looped forever and didnt register
    Also make sure to press hard on it
    [esp32_Wroom_fingertest.ino]
2024-11-20 Fully integrated Wroom RFID and fingerprint
2024-11-20 Lockbox Schematic and PCB Layout V2.1
    Near final!
2024-11-21 Updated wroom_lock_rfid.ino adding serial prints to show process
2024-11-21 PCB and Schematic V2.3
    Version 2.2 was not added due to its short lifespan
2024-11-27 Add files via upload
    Version Updates
    [Best.stl, odd.stl, realistic.stl]
2024-12-02 Updated fingerprint error text for wroom_lock_rfid.ino
    [wroom_lock_rfid.ino]
2024-12-03 Add files via upload
    Final Design
    [Box with holes.stl]
2024-12-03 Fixed header comments for Enroll_Only.ino
    [Enroll_Only.ino]
2024-12-10 Final BOM Revision
    Sorry this took so long, my bad. Should be accurate.
2024-12-11 Box Versions
    Stl files for the housing design
    [Other.stl, Print In Place.stl, v1.1.stl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]
2024-12-13 Deleted Old BOM
2024-12-13 All Altium Files
    [Fingerprint_Mechanism_PCB.PcbDoc, Fingerprint_Mechanism_PCB_V0.3.PcbDoc, Fingerprint_Mechanism_PCB_V0.4.PcbDoc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]
